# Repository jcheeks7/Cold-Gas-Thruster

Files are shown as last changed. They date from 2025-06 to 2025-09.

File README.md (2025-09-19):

# Cold Gas Propulsion System

A hands-on cold gas thruster project designed and built for fun. This repository includes the full design lifecycle: research, system modeling, simulation, documentation, CAD, and hardware test planning.

---

## 🚀 Project Overview

Cold gas propulsion is a simple, safe, and cost-effective technology for small spacecraft attitude and trajectory control. This system uses a compressed gas CO₂ expelled through a nozzle to generate thrust via Newton's Third Law.

This project models, simulates, and prepares for the physical implementation of a cold gas thruster, including hardware, controls, and testing protocols.

---

## 🚧 Current Progress🚧:

✅Literature Review <br>
✅Concept Design <br>
✅Design Choice Review <br>
✅Schematics <br>
✅Material Ordered <br>
✅Material Recieved <br>
✅Tool Kit <br>
✅Simulation (Toolkit & CFD) <br>
✅CAD <br>
✅Build <br>
✅Results <br>

---

## 📁 Repository Structure

```
cold-gas-propulsion/
├── docs/                  # Documentation and visual references
│   ├── CAD/               # SolidWorks and STEP files
│   ├── testing/           # Test plans, safety protocols
│   ├── schematics/        # System-level architecture diagrams (P&ID's, etc...)
│   ├── images/            # Graphics for README and LaTeX report
│   └── report/            # LaTeX project report (main.tex, sample.bib)
│
├── src/                   # Source code for simulation and analysis
│   └── python/            # System Simulation and Control Baord
│
├── data/                  # Experimental data, logs, CSV or .mat files
├── results/               # Output plots and figures
├── .gitignore
├── LICENSE
└── README.md              # You're here
```

---

## 🧠 Features

* Ideal gas and isentropic nozzle flow models
* Time-step tank pressure & mass simulation
* CAD-compatible tank layout and plumbing
* Full LaTeX technical report with citations
* P\&ID and testing documentation

---

## 🛠 Tools Used

* **Python** — Data simulation and valve control
* **SolidWorks / Fusion 360** — 3D modeling
* **LaTeX** — technical documentation
* **GitHub** — version control and publishing

---

## 📄 LaTeX Report

Location: [`docs/report/`](docs/report/)

To compile:

```bash
pdflatex main.tex
bibtex main
pdflatex main.tex
pdflatex main.tex
```

Includes:

* Literature survey (cold gas, CubeSat trends)
* Design rationale and equations
* Simulation results and plots
* Safety and testing methodology

---

## 📸 Showcase

*(Coming soon)*

* Annotated CAD screenshots
* Plot samples from simulation
* Build photos & test rig shots

---

## ✅ Future Work

*Nozzle Parameter Expirementation
*Toolkit Expansion

---

## 📜 License

[MIT License](LICENSE) — feel free to fork, remix, and learn from this project.

---

## 👨‍🚀 Author

Developed by Jaxsen Cheeks, a Georgia Tech aerospace engineering undergrad, for summer propulsion research and small satellite systems experience.

For questions, collabs, or feedback, feel free to reach out!
* jcheeks7@gatech.edu
* linkedin.com/jaxsenc

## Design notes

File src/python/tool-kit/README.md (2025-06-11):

# Cold Gas Propulsion Toolkit

A modular Python toolkit for modeling, sizing, and simulating cold gas propulsion systems. Designed for aerospace engineers and students to estimate performance, size hardware, and visualize system behavior from first principles.

---

## Features

* **Core Flow Modeling**: Calculates mass flow rate, exit velocity, Mach number, and thrust
* **Sizing Tools**: Computes required propellant mass, total impulse, tank volume, and achievable delta-v
* **Nozzle Design**: Supports Mach-area relationships, exit geometry, and expansion ratio analysis
* **Tank Modeling**: Ideal gas storage, MEOP calculation, and burst pressure estimation
* **Time-Step Simulation**: Models pressure and mass over time with plotting support

---
## Author

Developed by Jaxsen Cheeks — Aerospace Engineering @ Georgia Tech. Toolkit developed for academic and personal propulsion projects.

---

## Future Additions

* Multi-pulse burn simulation
* Streamlit GUI
* Unit testing
* CSV export for test reports

---

## Folder Structure

```
cold-gas-toolkit/
├── core/
│   ├── constants.py          # Global constants (Pt, Tt, gamma, R, etc.)
│   ├── flow.py               # Isentropic flow calculations
│   ├── thrust.py             # Thrust and Isp functions
│   ├── sizing.py             # Impulse, mass, delta-v, and tank volume
│   ├── tank.py               # Ideal gas modeling and burst pressure
│   └── simulation.py         # Time-step simulation of burn
├── examples/
│   ├── full_cold_gas_case.py     # End-to-end flow and sizing demo
│   ├── sizing_demo.py            # Propellant mass and delta-v
│   ├── tank_sizing_demo.py       # Pressure and burst calculations
│   └── plot_burn_simulation.py   # Pressure/mass vs time visualization
├── README.md
├── requirements.txt
└── .gitignore
```

---

## Installation

```bash
git clone https://github.com/your-username/cold-gas-toolkit.git
cd cold-gas-toolkit
pip install -r requirements.txt
```

---

## Requirements

* Python 3.7+
* `matplotlib`
* `scipy`

Install manually:

```bash
pip install matplotlib scipy
```

---

## Example Usage

Run a complete mission analysis:

```bash
python examples/full_cold_gas_case.py
```

Run a burn simulation and plot:

```bash
python examples/plot_burn_simulation.py
```

---

## License

MIT License

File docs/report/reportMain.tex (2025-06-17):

\documentclass{new-aiaa}
\usepackage[utf8]{inputenc}
\usepackage{graphicx}
\usepackage{amsmath}
\usepackage{siunitx}
\usepackage{hyperref}
\usepackage{booktabs}
\usepackage{amssymb}
\usepackage{float}

\title{Design, Simulation, and Testing of a Modular Cold Gas Thruster System for CubeSat Applications}

\author{Jaxsen Cheeks \thanks{Undergraduate Student, School of Aerospace Engineering, Georgia Institute of Technology, Atlanta, GA.}}

\begin{document}
\maketitle

\begin{abstract}
Cold gas propulsion systems offer a simple, reliable, and low-cost solution for small satellite maneuvering and attitude control. Utilizing pressurized inert gases such as carbon dioxide or nitrogen, these systems provide limited but highly controlled thrust, making them ideal for CubeSats and nanosatellites operating in low Earth orbit. This paper presents the design, simulation, and testing of a benchtop cold gas thruster system with an accompanying simulation toolkit, CAD design, and a literature-informed proposal, drawing inspiration from current academic and industrial advancements.
\end{abstract}

\section*{Nomenclature}
\begin{tabbing}
    $P_0$ \quad \= Stagnation (regulated input) pressure (Pa) \\
    $P_a$ \> Ambient pressure (Pa) \\
    $T_0$ \> Stagnation (input) temperature (K) \\
    $\gamma$ \> Specific heat ratio (isentropic exponent) \\
    $R$ \> Specific gas constant (J/kg$\cdot$K) \\
    $C_d$ \> Discharge coefficient \\
    $A_t$ \> Nozzle throat area (m$^2$) \\
    $d_t$ \> Nozzle throat diameter (m) \\
    $d_e$ \> Nozzle exit diameter (m) \\
    $A_e$ \> Nozzle exit area (m$^2$) \\
    $\dot{m}$ \> Mass flow rate (kg/s) \\
    $v_e$ \> Exhaust velocity (m/s) \\
    $F$ \> Thrust (N) \\
    $I_{sp}$ \> Specific impulse (s) \\
\end{tabbing}

\section{Introduction}

In recent years, the use of CubeSats and small satellites has grown rapidly due to their cost-effectiveness and versatility. Their smaller volume and lower costs both contribute to a simple equation that benefits industry giants and emerging ventures alike. Smallsats serve a wide range of purposes, including environmental data collection, telecommunications, and technological demonstrations, with operators hailing from academia, government agencies, and commercial enterprises. However, because these satellites are designed to be more compact than their traditional counterparts, manufacturers face significant constraints when adding subsystems beyond the satellite’s primary mission.

One of the major challenges for smallsat platforms is the development of reliable, efficient, and compact propulsion systems. Historically, many CubeSat missions opted out of incorporating propulsion, relying instead on deployment mechanisms or passive orbital decay. However, as mission complexity increases, the need for precise maneuvering, station keeping, and deorbiting has grown. Traditional propulsion systems, such as chemical and electric thrusters, provide high performance but are often unsuitable for CubeSats due to their complexity, cost, and safety concerns. Cold gas propulsion systems offer a promising alternative due to their simplicity, operational safety, and low cost, although they deliver lower performance than chemical or electric systems.

This paper presents the design, simulation, and testing of a modular benchtop cold gas thruster system developed as a proof of concept for CubeSat-scale propulsion applications. The project integrates hardware prototyping, CAD modeling, and a simulation toolkit using MATLAB and Python to predict system performance. Drawing inspiration from recent research by NASA and the Georgia Tech Space Systems Design Lab (SSDL), this work aims to demonstrate the feasibility of a compact, reliable, and low-cost propulsion solution for future small satellite missions.

\section{Background and Literature Review}

Cold gas propulsion systems use stored, pressurized inert gaseous or liquid propellant expelled through a nozzle to generate thrust. This process leverages the principle of isentropic expansion, where gas accelerates through the nozzle by converting potential energy (pressure) into kinetic energy (thrust) with no heat transfer and constant entropy \cite{nasa2021}. The nozzle geometry, particularly the throat and expansion ratio, plays a critical role in determining flow efficiency and performance. When the flow reaches sonic conditions (Mach 1) at the nozzle throat, it becomes choked, meaning the mass flow rate depends solely on upstream pressure and nozzle dimensions, ensuring predictable thrust output even in varying space conditions. 
\begin{figure}[h!]
    \centering
    
    \caption{Simplified nozzle diagram illustrating isentropic expansion and choked flow in a cold gas propulsion system.}
    \label{fig:nozzle}
\end{figure}

The simplicity of cold gas systems stems from their reliance on a single propellant fluid, eliminating the need for complex fuel-oxidizer systems or extensive power storage required by traditional chemical or electric propulsion \cite{nasa2021}. These characteristics result in propulsion solutions that are lighter, less complex, and more cost-effective, making them particularly attractive for CubeSat and small satellite missions constrained by mass, volume, and budget. Such systems are often chosen by universities, research institutions, and organizations developing exploratory or educational missions. However, cold gas systems do have inherent limitations, including lower specific impulse (typically 50–70 seconds), low thrust levels (on the order of millinewtons), and limited delta-v capacity \cite{khader2018space}.

Within recent years, studies from NASA \cite{nasa2021}, Khader et al. \cite{khader2018space}, and the Georgia Tech Space Systems Design Lab (SSDL) \cite{skidmore2016}-among others- have established a strong foundation for cold gas propulsion systems in small satellite missions. NASA's comprehensive report on small satellite propulsion systems highlights cold gas thrusters as a viable and reliable option for both altitude control and minor orbital maneuvers, emphasizing their simplicity and low complexity \cite{nasa2021}. Khader et al. provide a detailed review of micropropulsion technologies for CubeSats and small satellites, discussing cold gas thrusters alongside alternatives like resistojet and electric propulsion systems \cite{khader2018space}. Their work emphasizes cold gas systems' operational simplicity and safety, while acknowledging limitations in specific impulse and thrust permormance. Georgia Tech's SSDL has demonstrated a CubeSat-scale cold gas system for the SunRISE mission, featuring moduler design, Arduino-based control, and the use of krypton as its propellant \cite{skidmore2016}. Together, these studies provide a comprehensive background to support the exploration of this project. 

Recent research has focused on advancing cold gas propulsion technology to address its inherent limitations and expand its capabilities for small satellite missions \cite{nasa2021,khader2018space,skidmore2016,adelis2019}. Additive manufacturing techniques, such as 3D printing, have enabled the fabrication of complex nozzle geometries, improving gas flow efficiency and system compactness \cite{skidmore2016}. Microelectromechanical systems (MEMS) have been explored to develop micro-thrusters with precise control and scalability, opening new possibilities for formation flying and distributed satellite architectures \cite{khader2018space}. Modular and plug-and-play propulsion systems, like those used in Adelis-SAMSON, have facilitated integration into diverse CubeSat platforms while reducing development time \cite{adelis2019}. Despite these innovations, cold gas systems remain limited by their low specific impulse and total impulse, constraining their use to attitude control and minor orbital adjustments \cite{nasa2021,khader2018space}. Future research is likely to focus on hybrid systems, improved propellant storage designs, and nozzle optimization to enhance performance while maintaining simplicity and safety \cite{nasa2021,khader2018space}.

This project builds upon these ongoing research efforts, drawing insights from NASA’s reports, the comprehensive review by Khader et al., and the Georgia Tech Space Systems Design Lab’s work. By integrating hardware prototyping, simulation modeling, and CAD design, this modular benchtop cold gas thruster system provides a practical demonstration platform for CubeSat-scale propulsion development. Additionally, the project offers educational value, serving as a practical, hands-on application of coursework and extracurricular knowledge.

\section{System Design}

The benchtop cold gas thruster system for this project is structured into five key subsystems: propellant and propellant storage, flow control, nozzle assembly, electronics and control logic, and system mounting with integrated safety measures. The following subsections outline each component's design considerations and implementation.

\subsection{Propellant and Storage System}
\subsubsection{Propellant Choice}
The propellant selected for this cold gas thruster system is carbon dioxide (CO$_2$), chosen for its safety, availability, and ease of use, especially for a student-level. Given the constraints of limited manufacturing capabilities, budget considerations, and reliance on consumer-accessible products, the choice prioritized safety and simplicity. Non-flammable, low-toxicity propellants such as R-134a and CO$_2$ emerged as ideal candidates, with CO$_2$ being widely available through consumer-grade sources like SodaStream and paintball cartridges. These options provide a balance of affordability (R-134a: $\sim\$10$–30; CO$_2$: $\sim\$10$–50) and compatibility with readily available tanks and valves \cite{nasa2021,khader2018space,skidmore2016}. While compressed air offers the safest and simplest approach, its lower performance limits its suitability for propulsion testing. Higher-performance but flammable options such as butane and propane were considered but ultimately rejected due to safety concerns, particularly in a home setting. This rationale highlights the trade-offs made to achieve a safe, functional, and cost-effective cold gas propulsion system for student-level experimentation.

\begin{table}[h!]
\centering
\caption{Cold Gas Propellant Candidates for Home Builds}
\begin{tabular}{@{}llllll@{}}
\toprule
\textbf{Propellant} & \textbf{Safety} & \textbf{Availability} & \textbf{Complexity} & \textbf{Cost} \\ \midrule
\textbf{R-134a} & Non-flammable &  Auto AC refrigerant & Simple & \$10--30 \\
\textbf{CO$_2$} &  Non-flammable, inert &  SodaStream, paintball & Simple (adapters) & \$10--50 \\
\textbf{Compressed Air} &  Safe &  Air compressor/tanks & Simple & Very low\\
\textbf{Butane} &  Flammable &  Camping canisters & Low (adapters) & \$3--10\\
\textbf{Propane} &  Flammable &  Camping tanks & Moderate & \$10--20 \\
\textbf{Nitrogen (N$_2$)} &  Inert, safe &  Welding suppliers & Moderate & \$50--100 \\
\bottomrule
\end{tabular}
\end{table}

\subsubsection{Propellant Storage Tank}
The cold gas system utilizes a commercially available 12oz CO$_2$ paintball tank. This type of tank was selected due to its widespread availability, ease of handling, and compatibility with common regulators and consumer-grade hardware. The tank is safety-certified (DOT, CE) for high-pressure gas storage and is designed to handle approximately 800 psi (55 bar) at room temperature. Its built-in regulator and standardized fittings ensure safe and convenient integration into the propulsion system, while providing sufficient volume for experimental cold gas propulsion tests.

\subsubsection{Pressure Regulator}
A commercially available, adjustable paintball CO$_2$ regulator was selected for the system. This regulator is designed for use with 12oz CO$_2$ paintball tanks and supports an output pressure range of 0–300 psi. For safe testing and controlled propellant flow, the regulator output is set to approximately 50–100 psi. This range provides sufficient thrust for experimental propulsion tests while ensuring low-pressure, safe operating conditions. The regulator is widely available through online retailers and sporting goods stores and is compatible with the paintball tank's standard CGA 320 thread, ensuring a secure and reliable connection.

\subsubsection{Tubing and Fittings}

The tubing selected for the system is PTFE (Teflon), chosen for its excellent chemical resistance, smooth internal surface, and moderate pressure capability suitable for CO$_2$ use. The tubing has a 1/4" outer diameter (OD), providing a balance of flexibility, flow capacity, and ease of handling. Compression fittings made of brass or stainless steel are used to secure the tubing, ensuring a reliable and leak-free connection under system pressure. Both the PTFE tubing and compression fittings are rated for pressures well above the system's nominal operating range of 50–100 psi, offering a significant safety margin.

\subsection{Flow Control Subsystem}

The flow control subsystem incorporates a 12V DC solenoid valve rated for moderate pressures (up to 100 psi), selected for its compatibility with CO$_2$ and commercial availability. The valve is actuated by an Arduino microcontroller through a logic-level N-channel MOSFET switch, allowing precise control of firing duration and system operation. A 12V DC power supply provides power to the solenoid valve, while the Arduino is powered separately via USB or a dedicated 5V supply. A flyback diode is included across the solenoid terminals to protect the electronics from voltage spikes during valve deactivation. No pressure sensor is included in the flow path, as the system’s performance can be monitored through controlled regulator settings and propellant flow rates.

\subsection{Nozzle Design and Fabrication}

The nozzle used in this cold gas propulsion system is a converging–diverging (C–D) nozzle, designed to facilitate efficient expansion of CO$_2$ gas. The geometry consists of a smooth converging section leading to a narrow throat (2 mm diameter), followed by a diverging exit (4 mm diameter). This configuration is based on classical compressible flow theory and enables the flow to reach Mach 1 at the throat under choked conditions, with potential for supersonic expansion in the diverging section if pressure conditions allow.

The design calculations assume isentropic flow and ideal gas behavior. The nozzle was modeled using SolidWorks and fabricated via 3D printing using high-strength PETG, chosen for its durability and chemical resistance.

\vspace{0.5em}
\noindent
\textbf{Design Parameters (Table~\ref{tab:nozzleparams}):}

\begin{table}[h]
\centering
\caption{C–D Nozzle Design Parameters}
\label{tab:nozzleparams}
\begin{tabular}{ll}
\toprule
\textbf{Parameter} & \textbf{Value} \\
\midrule
Propellant & CO$_2$ \\
Chamber Pressure ($P_0$) & 50 psi $\approx$ 344,738 Pa \\
Ambient Pressure ($P_a$) & 1 atm = 101,325 Pa \\
Temperature ($T_0$) & 293 K \\
Specific Heat Ratio ($\gamma$) & 1.3 \\
Gas Constant for CO$_2$ ($R$) & 188.9 J/kg·K \\
Discharge Coefficient ($C_d$) & 0.9 \\
Throat Diameter & 2 mm \\
Exit Diameter & 4 mm \\
\bottomrule
\end{tabular}
\end{table}

\vspace{0.5em}
\noindent

\vspace{0.5em}
\noindent
The nozzle is mounted to the propulsion system using a compression fitting for 1/4" OD tubing. Post-processing steps such as sanding were applied to smooth the internal walls and reduce turbulence. This design allows for safe, testable cold gas expansion under ambient conditions, while approximating the performance of a space-bound cold gas thruster.

\subsubsection{Calculated Performance}
\noindent\textbf{Throat Area:}
\[
A_t = \pi r_t^2 = \pi (0.001)^2 = 3.14 \times 10^{-6} \ \text{m}^2
\]
\noindent\textbf{Mass Flow Rate:}
\[
\dot{m} = C_d A_t P_0 \sqrt{\frac{\gamma}{R T_0}} \left( \frac{2}{\gamma+1} \right)^{\frac{\gamma+1}{2(\gamma-1)}} \approx 5.08 \times 10^{-4} \ \text{kg/s}
\]
\noindent\textbf{Exhaust Velocity:}
\[
v_e = \sqrt{\frac{2 \gamma R T_0}{\gamma - 1}} \approx 693 \ \text{m/s}
\]
\noindent\textbf{Thrust:}
\[
F = \dot{m} v_e \approx 0.353 \ \text{N}
\]
\noindent\textbf{Specific Impulse:}
\[
I_{sp} = \frac{F}{\dot{m} g_0} \approx 70.8 \ \text{s}
\]

\subsubsection{Modeling}
The nozzle geometry was modeled in SolidWorks, defining the throat and exit diameters with a smooth converging contour to minimize flow separation and turbulence. Fabrication was performed using a Prusa i3 MK3 3D printer, with PETG selected for its resistance to CO$_2$, durability, and moderate pressure capacity. Post-processing (light sanding) was applied to smooth internal surfaces and enhance flow characteristics. The nozzle is connected to the system using a brass compression fitting for 1/4" OD tubing, ensuring a secure, leak-free interface with the solenoid valve output.

\subsection{Microcontroller and Electronics Control}

The propulsion system’s electronics are controlled by an Arduino Uno microcontroller, which serves as the central unit for actuating the solenoid valve. A digital output pin from the Arduino switches a logic-level N-channel MOSFET (e.g., IRLZ44N), controlling the 12V power supply to the valve and enabling precise actuation based on Arduino logic. Pulse timing for the solenoid valve is implemented via Arduino code, regulating firing duration to control propellant flow during tests.

Power is provided by a 12V DC supply (e.g., wall adapter or battery pack) for the solenoid valve and a separate USB or 5V DC supply for the Arduino, ensuring isolated control and actuation circuits. Protective components include a flyback diode (e.g., 1N4007) across the solenoid terminals to prevent voltage spikes caused by coil deactivation, and an optional current-limiting resistor in the MOSFET gate connection for signal conditioning, though the Arduino’s digital pin typically drives the MOSFET gate directly.

The circuit is initially assembled on a breadboard for prototyping and testing, with plans to transition to a more durable protoboard after validation. This approach provides safe, reliable, and adjustable operation of the cold gas propulsion system using standard, readily available components and prototyping methods.

\subsection{System Mounting and Safety Measures}

All system components will be mounted on a rigid plywood baseplate, manufactured to accommodate the system layout and provide easy access for assembly and testing. Components will be securely fixed to the baseplate using a combination of metal brackets, hose clamps, and zip ties to prevent movement during operation. Compression fittings will be used for tubing connections, ensuring leak-free seals and robust mechanical connections. Key components, including the solenoid valve and regulator, will be anchored directly to the baseplate to minimize vibrations and the risk of accidental disconnections.

Safety measures incorporated into the system include a pressure relief valve or pre-set regulator to ensure system pressure does not exceed the rated limits of the tubing and components (nominally 100 psi). Testing will be conducted in a controlled, outdoor workspace, clear of flammable materials and with adequate ventilation. Appropriate personal protective equipment (PPE), including safety glasses and gloves, will be used during all assembly and testing operations to mitigate potential hazards. These measures collectively ensure safe and reliable operation of the cold gas propulsion system under test conditions.

\subsection{System Architecture}

To summarize the complete cold gas propulsion system architecture, a Piping and Instrumentation Diagram (P\&ID) is provided in Figure~\ref{fig:pid}. This schematic integrates all major components discussed in the previous sections, including the propellant tank (PT-01), regulator (PPR-01), solenoid valve (PPV-01), control electronics (CTRL-01), and nozzle (N-01). The diagram also includes key safety features such as a pressure relief valve (PRV-01) and in-line pressure monitoring (PG-01), as well as the power supply interfaces (PS-01 and PS-02).

The P\&ID illustrates both fluid flow (CO$_2$) and electrical control pathways, highlighting how each subsystem interconnects during operation. Control signals from the microcontroller actuate the solenoid valve to regulate thrust, while regulated CO$_2$ flows from the tank through the valve and nozzle to generate impulse. The full component tag legend is provided in Table~\ref{tab:pid-legend}.

\begin{figure}[H]
\centering
\begin{minipage}{0.7\textheight}
    \centering
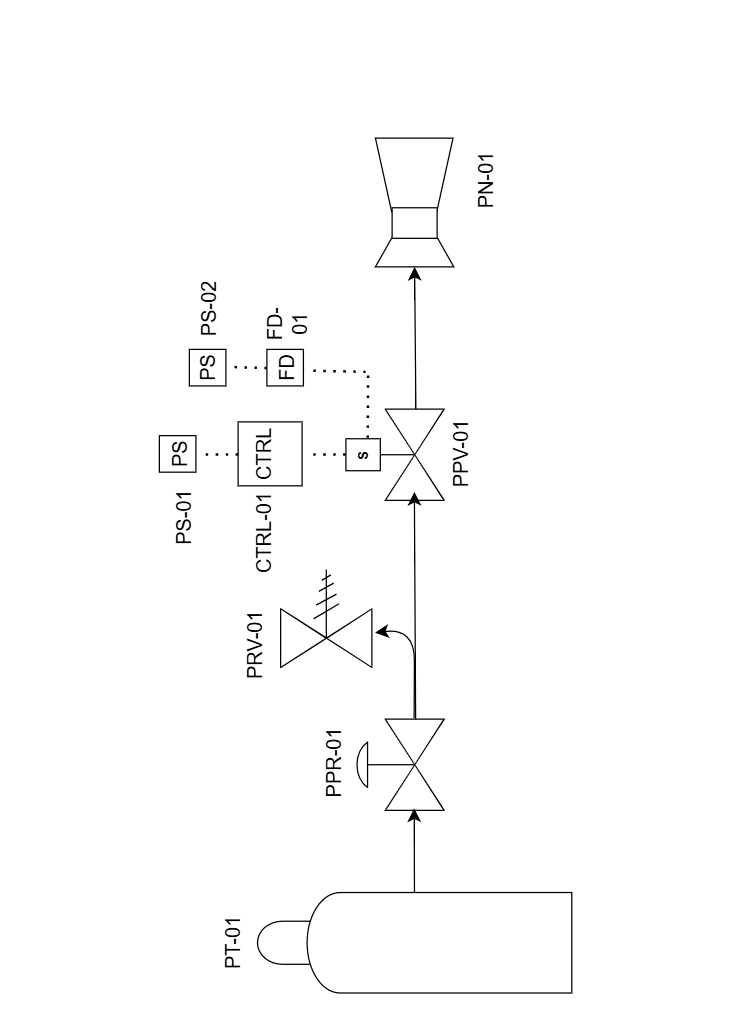
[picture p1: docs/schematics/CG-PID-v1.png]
     
    \caption{Piping and Instrumentation Diagram (P\&ID) for the cold gas propulsion system.}
    \label{fig:pid}
\end{minipage}
\hfill
\begin{minipage}{0.45\textheight}
    \centering
    \captionof{table}{P\&ID Component Legend}
    \begin{tabular}{lll}
        \toprule
        \textbf{Tag} & \textbf{Component} & \textbf{Notes} \\
        \midrule
        PT-01 & CO$_2$ Tank & 12oz, 800 psi \\
        PPR-01 & Regulator & 50–100 psi output \\
        PRV-01 & Pressure Relief Valve & Cracks at ~100 psi \\
        PPV-01 & Solenoid Valve (NC) & 12V, Arduino controlled \\
        CTRL-01 & Microcontroller & Arduino Uno \\
        FD-01 & Flyback Diode & 1N4007 \\
        PS-01 & Power Supply & 12V for solenoid \\
        PS-02 & Power Supply & USB/5V for Arduino \\
        PG-01 & Pressure Gauge & Upstream of nozzle \\
        PN-01 & Nozzle & 2 mm throat, 4 mm exit \\
        \bottomrule
    \end{tabular}
    \label{tab:pid-legend}
\end{minipage}
\end{figure}

\section{Integration and Testing}

\subsection{System Assembly}
The system assembly follows a structured order of operations:
\begin{enumerate}
    \item Mount the plywood baseplate and attach all components, including the CO$_2$ tank, regulator, solenoid valve, tubing, and nozzle.
    \item Secure tubing connections using compression fittings and clamps.
    \item Wire the Arduino, MOSFET, solenoid valve, and protective components on a breadboard.
    \item Connect power supplies: 12V for the solenoid valve, and USB or 5V for the Arduino.
    \item Perform pre-checks for wiring integrity and mechanical security, including:
    \begin{itemize}
        \item Verifying all fittings are properly tightened.
        \item Confirming correct wiring connections.
        \item Double-checking regulator pressure settings and valve orientation.
    \end{itemize}
\end{enumerate}

\subsection{Testing Procedures}
A series of tests will be conducted to ensure system functionality and safety:
\begin{itemize}
    \item \textbf{Leak Test}: Apply soapy water or use a gas leak detector on all tubing and fittings prior to pressurization.
    \item \textbf{Valve Function Test}: Verify solenoid valve operation in response to Arduino commands at low pressure.
    \item \textbf{Nozzle Performance Test}: Observe and evaluate the CO$_2$ jet for thrust and flow characteristics.
    \item \textbf{Timing Test}: Measure valve response time and actuation duration controlled by Arduino timing functions.
\end{itemize}

\subsection{Performance Monitoring}
\begin{itemize}
    \item \textbf{Pressure Monitoring}: Use a pressure gauge upstream of the nozzle or monitor regulator output to confirm operating pressure.
    \item \textbf{Flow Observation}: Visually observe the nozzle’s exhaust plume during tests.
    \item \textbf{Timing Measurements}: Use a stopwatch or Arduino timing functions to measure valve open duration and response times.
\end{itemize}

\subsection{Safety Procedures}
Safety measures implemented during testing include:
\begin{itemize}
    \item Conducting tests in a well-ventilated, outdoor workspace free of flammable materials.
    \item Wearing safety glasses and gloves during all testing operations.
    \item Beginning with low-pressure testing before gradually increasing to full operating conditions.
    \item Being prepared to disconnect power or shut off the regulator in case of malfunction.
    \item Never leaving the system unattended while pressurized or during tests.
\end{itemize}

\section{Simulation Toolkit}

The system’s performance and design calculations were modeled using  \textbf{Python}. The simulation toolkit includes several key computational modules:

\subsubsection{Key Functions}
\begin{itemize}
    \item Isentropic flow calculations to determine choked flow conditions.
    \item Mass flow rate estimation based on throat area and regulator pressure.
    \item Exhaust velocity and specific impulse modeling.
    \item Thrust estimation derived from mass flow rate and exhaust velocity.
\end{itemize}

\subsubsection{Simulation Inputs}
\begin{itemize}
    \item Upstream regulated pressure ($P_0$), e.g., 50 or 100 psi.
    \item Ambient temperature ($T_0$), e.g., 293 K ( or whatever temp on test day is)
    \item Nozzle throat area ($A_t$:\[ 3.14 \times 10^{-6} \ \text{m}^2\]
    \item Gas properties for CO$_2$: specific gas constant ($R$) and heat ratio ($\gamma$).
\end{itemize}

\subsubsection{Simulation Outputs}
\begin{itemize}
    \item Mass flow rate ($\dot{m}$) in kg/s.
    \item Exhaust velocity ($v_e$) in m/s.
    \item Thrust ($F$) in N.
    \item Specific impulse ($I_{sp}$) in s.
    \item Flow condition: choked or un-choked.
\end{itemize}

\subsubsection{Validation}
Validation of the simulation outputs was conducted through:
\begin{itemize}
    \item Comparison with theoretical predictions from compressible flow equations.
    \item Cross-checking of calculated thrust and mass flow rates with experimental test data (e.g., valve timing tests, nozzle flow observations).
    \item Qualitative comparison of simulated nozzle performance (plume behavior) with actual observations from experimental tests.
\end{itemize}

This simulation toolkit provides an effective means to predict, analyze, and refine system performance both before and during experimental operations.

\section{Results and Discussion}
key findings from build and tests, simulation results vs real-world data, system performance analysis, and lessons learned

\section{Conclusion and Future Work}
summary of contributions, system performance, and potential extensions to hybrid or green propulsion systems, and integration with CubeSat missions
could expand into experimenting with nozzle variations; nozzle throat diameter, nozzle exit diameter, convergent(current) vs divergent-convergent vs divergent

\bibliographystyle{new-aiaa}
\bibliography{reportBib}

\end{document}

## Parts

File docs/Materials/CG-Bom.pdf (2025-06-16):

Item | Category | Link | Price | Quantity | Notes
12oz CO₂ Paintball Tank | Hardware | CO2 Tank (https://www.amazon.com/dp/B08LKBWR6Y?psc=1&ref_=cm_sw_r_cp_ud_ct_5755XG9B5F1YQAE959AT_5) | 30 | 1 Standard CO₂ storage
CO₂ Regulator | Hardware | CO2 Reg (https://www.amazon.com/dp/B0D53JV378?psc=1&ref_=cm_sw_r_cp_ud_ct_5755XG9B5F1YQAE959AT_4) | 60 | 1 Adjustable regulator
PTFE Tubing (1/4" OD) | Hardware | 1/4" OD PTFE (https://www.amazon.com/dp/B07K7T67CQ?psc=1&ref_=cm_sw_r_cp_ud_ct_5755XG9B5F1YQAE959AT_1) | | 20 1 roll | Chemical resistant
PTC 1/4" OD to NPT; PTC 1/4" OD Kit | Hardware | PTC2NPT; PTC Kit | | 5 10pk;60pk | Leak-proof connections
12V DC Solenoid Valve | Hardware | 12V DC Solenoid Valve (https://www.amazon.com/dp/B08N9R2QYJ?psc=1&ref_=cm_sw_r_cp_ud_ct_5755XG9B5F1YQAE959AT) | 15 | 1 Valve for flow control
Raspberry Pi 5 | Electronics | Already Have | | | 1 Microcontroller
IRLZ44N MOSFET | Electronics | IRLZ44N MOSFET (https://www.amazon.com/dp/B08LKBWR6Y?psc=1&ref_=cm_sw_r_cp_ud_ct_5755XG9B5F1YQAE959AT_5) | | 10 5-pack | Controls solenoid
12V DC Power Supply | Electronics | 12V DC PS - Solenoid (https://www.amazon.com/Adapter-100-240V-Transformer-Charger-Security/dp/B091XSVV1Y) | 15 | 1 Powers solenoid
Flyback Diode (1N4007) | Electronics | Fly Back Diode (https://www.amazon.com/BOJACK-Rectifier-IN4007-Electronic-Silicon/dp/B07Q6J9TNW?sp_csd=d2lkZ2V0TmFtZT1zcF9hdGY) | | 5 10-pack | Protects circuit
Breadboard | Electronics | Bread Board (https://www.amazon.com/dp/B01EV6LJ7G) | 7 | 1 For prototyping
Jumper Wires & Resistors | Electronics | Resistors; Jumper Wires | | 10 As needed | For connections
Plywood Baseplate | Hardware | Have | 10 | 1 Custom-cut mounting
Mounting Hardware | Hardware | Have | | 10 As needed | Brackets, clamps, zip ties
Pressure Relief Valve | Safety | Relief Valve - 110 PSI (https://www.amazon.com/Brass-Industrial-Safety-Pressure-Relief/dp/B0B3PB2H32) | 20 | 1 Ensures safe pressure
Piping Hardware | Safety | 15 | 1 Monitors system pressure
Safety Glasses & Gloves | Safety | Have | | 0 1 set | Personal protection
Leak Detection Solution | Safety | 5 | 1 Check for leaks
3D Printer & PETG Filament | Tools | GaTech Makerspace | 0 | 1 For nozzle fabrication
MATLAB | Software | Have | | 0 - | Simulation toolkit
Python (Optional) | Software | Have | | 0 - | Visualization and analysis
Raspberry Pi IDE | Software | Have | | 0 - | For microcontroller code
Digital Scale (Optional) | Testing | Have | 0 | 1 Estimate thrust by recoil
Outdoor Workspace Setup | Testing | Have | 0 | 1 Safe testing area
TOTAL | 237

# Cold Gas BOM

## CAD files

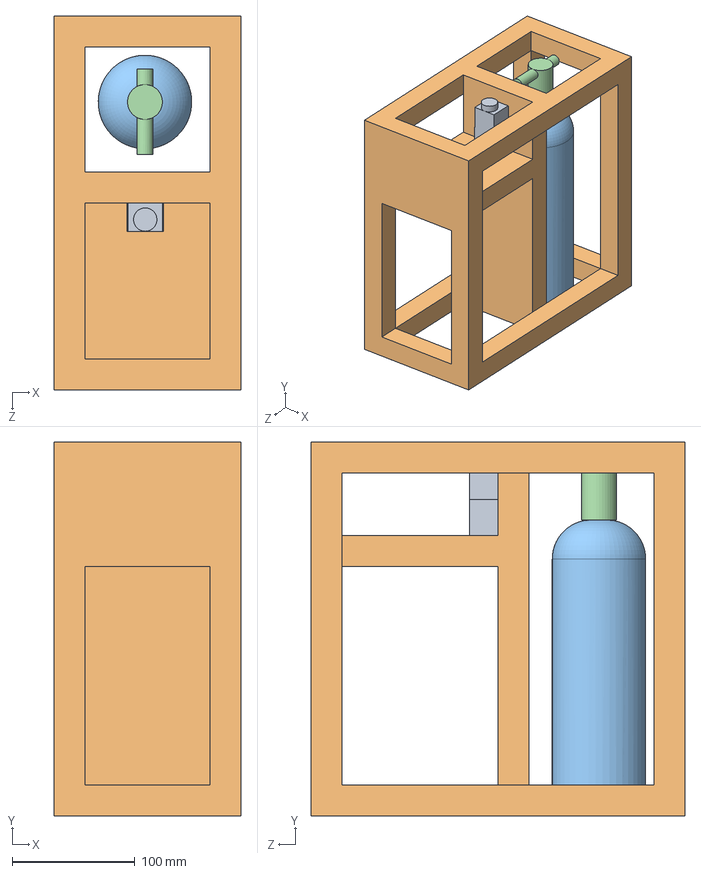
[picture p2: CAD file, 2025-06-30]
docs/CAD/Assem1.SLDASM
152.4 x 304.8 x 304.8 mm
CO2_REGULATOR
CO2_TANK
CRATE
SOLEDOIN

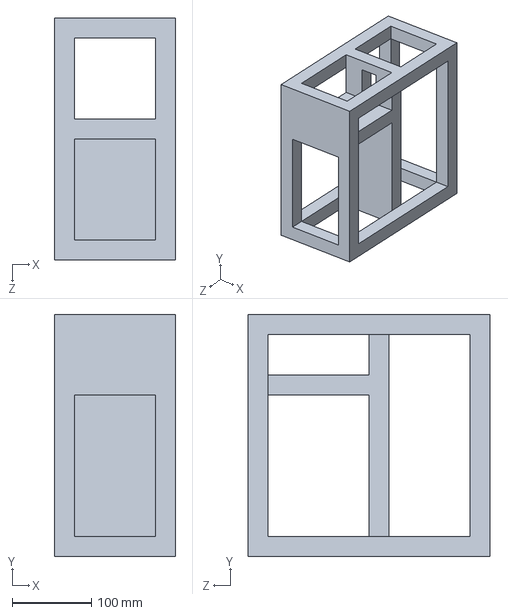
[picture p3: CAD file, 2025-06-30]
docs/CAD/CRATE.SLDPRT
152.4 x 304.8 x 304.8 mm

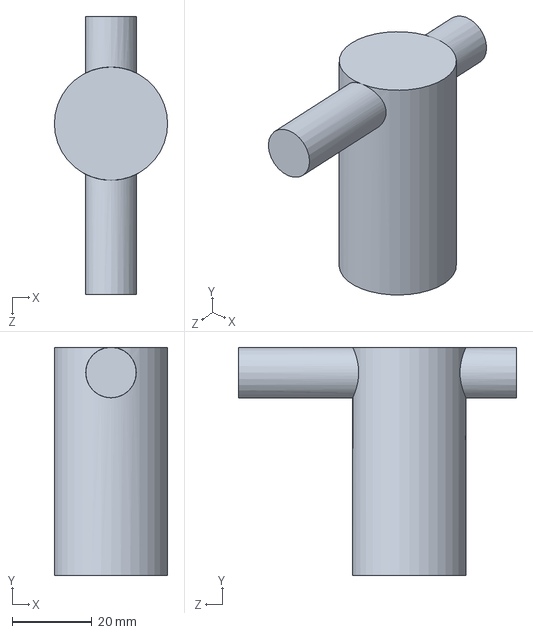
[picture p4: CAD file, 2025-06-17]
docs/CAD/CO2_REGULATOR.SLDPRT
28.4 x 57.4 x 69.8 mm

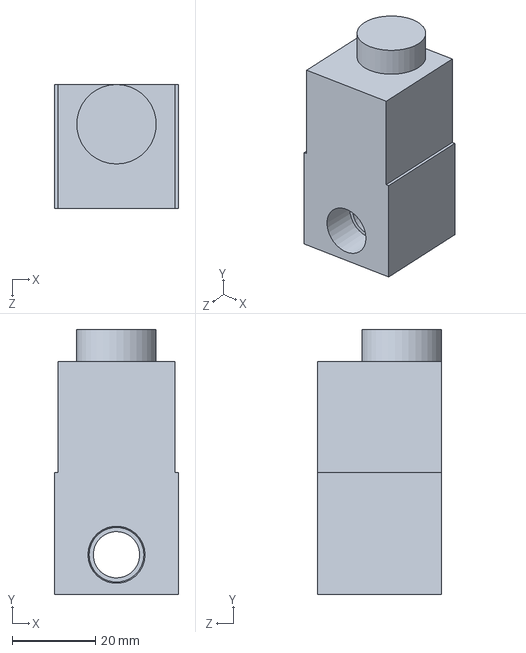
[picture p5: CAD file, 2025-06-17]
docs/CAD/SOLEDOIN.SLDPRT
29.7 x 63.5 x 29.7 mm

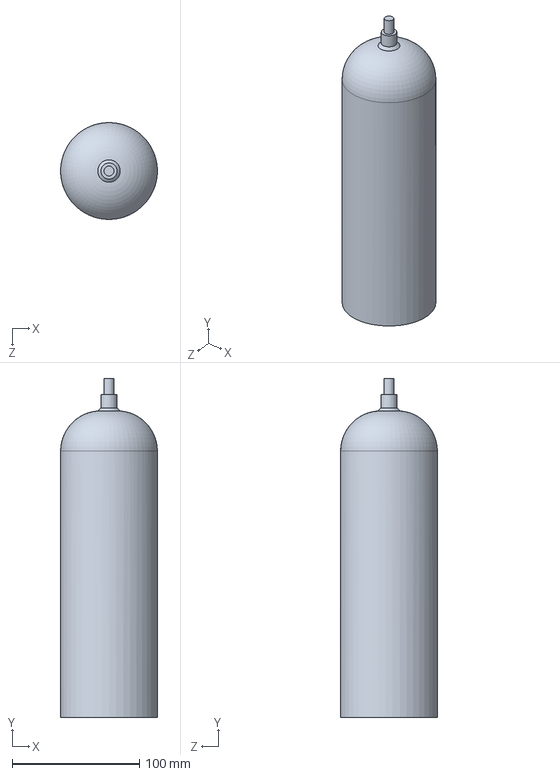
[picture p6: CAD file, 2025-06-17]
docs/CAD/CO2_TANK.SLDPRT
76.2 x 266.7 x 76.2 mm

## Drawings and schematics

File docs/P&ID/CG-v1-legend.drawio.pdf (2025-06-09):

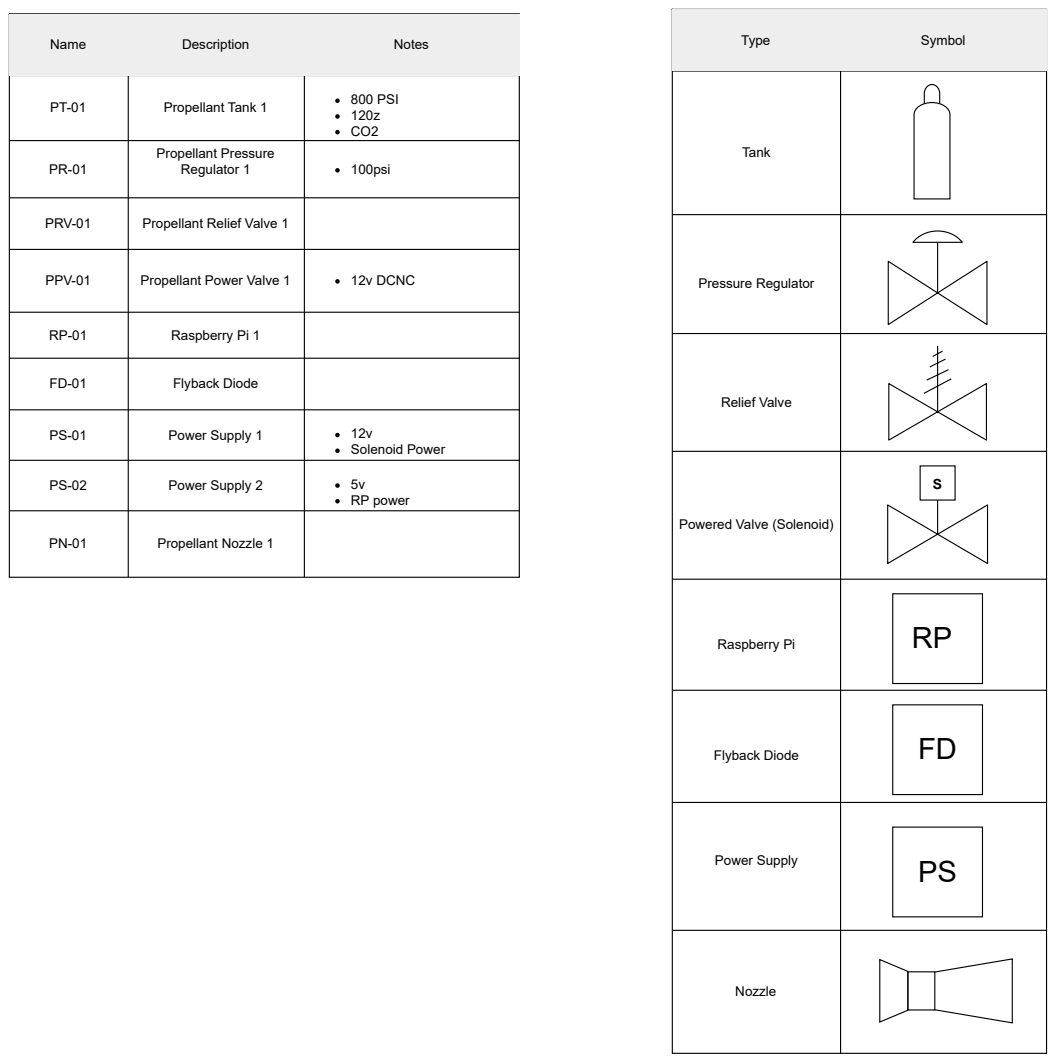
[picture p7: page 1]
Name; Description; Notes; Propellant Tank 1; 800 PSI; Propellant Pressure; Regulator 1; 100psi; PRV-01; Propellant Relief Valve 1; PPV-01; Propellant Power Valve 1; 12v DCNC; Raspberry Pi 1; Flyback Diode; Power Supply 1; Solenoid Power; Power Supply 2; RP power; Propellant Nozzle 1; Type; Symbol; Nozzle; Tank; Pressure Regulator; Relief Valve; Raspberry Pi; Power Supply

Powered Valve (Solenoid)

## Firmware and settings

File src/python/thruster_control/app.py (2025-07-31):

from flask import Flask, render_template, request
from gpio_control import fire_valve
import csv, os
from datetime import datetime

app = Flask(__name__)
LOG_FILE = "logs/events.csv"
os.makedirs("logs", exist_ok=True)
if not os.path.exists(LOG_FILE):
    with open(LOG_FILE, "w", newline="") as f:
        csv.writer(f).writerow(["timestamp","duration"])

@app.route("/", methods=["GET","POST"])
def index():
    message = None
    if request.method == "POST":
        try:
            duration = float(request.form["duration"])
            fire_valve(duration)  # actual GPIO pulse
            ts = datetime.now().strftime("%Y-%m-%d %H:%M:%S")
            with open(LOG_FILE, "a", newline="") as f:
                csv.writer(f).writerow([ts, duration])
            message = f"✅ Fired for {duration:.1f}s"
        except Exception as e:
            message = f"❌ Error: {e}"

    # load last 5
    logs = []
    with open(LOG_FILE) as f:
        rows = list(csv.DictReader(f))
        logs = rows[-5:]
    return render_template("index.html", message=message, logs=logs)

if __name__ == "__main__":
    app.run(host="0.0.0.0", port=5000)

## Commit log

2025-05-24 Create CAD
2025-06-11 Update sizing.py
    Added equations to calculate total impulse, propellant required, tank volume, and delta-V
2025-06-11 Create nozzle.py
    Adding nozzle.py script to model nozzle functions
2025-06-11 Update and rename nozzle.py to flowy.py
2025-06-11 Update and rename flowy.py to flow.py
    Update equations
2025-06-11 Update thrust.py
    Added equations
2025-06-11 Create flow_thrust_example.py
    Added initial equations
2025-06-11 Update flow_thrust_example.py
    Update Expansion_ratio and A_exit to import from constants
2025-06-11 Create gpio_control.py
    added initial valve firing logic
2025-06-12 Create pid
2025-06-12 Create BOM
2025-06-17 Added Reg, Tank, Solenoid
    Haha the part name should be SOLENOID, not SOLEDOIN
    [CO2_REGULATOR.SLDPRT, CO2_TANK.SLDPRT, SOLEDOIN.SLDPRT]
2025-06-17 Update README.md
    Added Current Progress
2025-06-30 Add files via upload
    Added crate and full asm
    [Assem1.SLDASM, CRATE.SLDPRT]
